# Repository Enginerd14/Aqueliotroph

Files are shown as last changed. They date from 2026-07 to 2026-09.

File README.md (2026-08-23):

# Aqueliotroph
Automated plant watering and sun tracking system to optimise conditions for growth

I made this project becuase I always forget to water my plants and they never get enough sunlight. As a result they never survive :(. The Aqueliotroph system directly combats this by moving the plant to optimise light and watering the plant when soil mositure is low. 

Inspiration behind the Name: 



## 3D model



## Schematic





## PCB







# Parts List

> **Note:** Only the PCB needs to be purchased. I already have all other parts available, so the cost should only be around **£5 / $7**.

| Item | Qty | Need to Buy | Price (£) | Link | Total (£) | Total ($) |
|---|---:|:---:|---:|---:|---:|---
| 600mm Aluminium extrusion | 1 | No | £7.00 | [Al extrusion 600mm](https://www.ebay.co.uk/itm/305167092557?var=604105049024) |52.67 |71.84
| Belt Pulley | 1 | No | £4.99 | [Belt Pulley](https://www.aliexpress.com/item/1005010636842055.html) |
| Belt idler | 1 | No | £3.85 | [Idler Pulley](https://www.aliexpress.com/item/1005008093251681.html) |
| V Wheels | 4 | No | £2.44 | [V Wheels](https://www.aliexpress.com/item/1005004275676552.html) |
| Flexible plastic tube | 1 | No | £1.47 | [PVC tube](https://www.aliexpress.com/item/1005009698880250.html) |
| DC motor | 1 | No | £2.12 | [DC pump 12V 60RPM](https://www.ebay.co.uk/itm/226921983677?var=526075182200) |
| DC Water Pump | 1 | No | £2.48 | [DC water pump](https://www.aliexpress.com/item/1005007587818206.html) |
| Limit Switches | 2 | No | £1.23 | [Limit switches](https://www.aliexpress.com/item/1005005924250789.html) |
| Moisture sensor | 1 | No | £2.59 | [Soil moisture sensor](https://www.ebay.co.uk/itm/235973021747?var=536444158439) |
| Wire | 1m | No | £0.80 | [Wire](https://www.aliexpress.com/item/1005007251965003.html) |
| 470µF and 0.1µF Capacitor | 3 | No | £3.99 | [Capacitors](https://www.ebay.co.uk/itm/227351789982?var=526553493681) |
| LCD Display | 1 | No | £2.21 | [LCD](https://www.aliexpress.com/item/1005005095893869.html) |
| 12V 3A power supply | 1 | No | £4.06 | [Power supply 12V 3A](https://www.aliexpress.com/item/4000494270389.html) |
| L293D | 1 | No | £1.36 | [L293D](https://www.aliexpress.com/item/1005010400118009.html) |
| Arduino Uno | 1 | No | £3.22 | [Arduino Uno R3](https://www.aliexpress.com/item/32768431306.html) |
| LDR | 1 | No | £0.84 | [LDR](https://www.aliexpress.com/item/1005008904534544.html) |
| 10K, 220Ω Resistor | 2 | No | £1.75 | [Resistors](https://www.aliexpress.com/item/32698175464.html) |
| 250K Potentiometer | 1 | No | £1.27 | [Potentiometer](https://www.aliexpress.com/item/1005009882075493.html) |
| **PCB** | **1** | **Yes** | **£5.00** | N/A |

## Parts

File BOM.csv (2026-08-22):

Item | Qty | Need to buy | Total Price £ | URL | TOTAL (£) | TOTAL ($) | Note: Only need to buy PCB as I have all other parts so total needed will be around $7
600mm Aluminium extrusion | 1 | N | 7 | Al extrusion 600mm | 52.67 | 71.84
Belt Pulley | 1 | N | 4.99 | Belt Pulley
Belt idler | 1 | N | 3.85 | Idler Pully
V Wheels | 4 | N | 2.44 | V Wheels
Flexible plastic tube | 1 | N | 1.47 | PVC tube
DC motor | 1 | N | 2.12 | DC pump 12v 60rpm
DC water Pump | 1 | N | 2.48 | DC water pump
Limit Switches | 2 | N | 1.23 | Limit switches
Moisture sensor | 1 | N | 2.59 | Soil moisture sensor
Wire | 1m | N | 0.8 | Wire
470uf and 0.1uf Capacitor | 3 | N | 3.99 | Capacitors
LCD Display | 1 | N | 2.21 | LCD
12V 3A power supply | 1 | N | 4.06 | Power supply 12V 3A
L293D | 1 | N | 1.36 | l293d
Arduino uno | 1 | N | 3.22 | arduino uno r3
LDR | 1 | N | 0.84 | LDR
10K, 220 Resistor | 2 | N | 1.75 | Resistors
250K Potentiometer | 1 | N | 1.27 | Potentiometer
PCB | 1 | Y | 5 | N/A

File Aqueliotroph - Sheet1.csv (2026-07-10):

Item | Qty | Need to buy | Total Price £ | URL | TOTAL (£) | TOTAL ($)
600mm Aluminium extrusion | 1 | N | 0 | N/A | 20.59 | 27.6
Driver Pulley | 1 | N | 0 | N/A
Idler Pulley | 1 | N | 0 | N/A
Flexible plastic tube | 1 | Y | 1.62 | ID8 x OD10mm Flexible pipe
DC motor | 1 | Y | 2.01 | 12V DC 60rpm motor
DC water Pump | 1 | Y | 3.33 | 12V DC water pump
Limit Switches | 3 | Y | 1 | 5pcs Limit Switches
Moisture sensor | 1 | Y | 0.59 | Moisture Sensor
470uf Capacitor | 2 | Y | 1.15 | 10pcs 470uf Capacitor
0.1uf Capacitor | 1 | Y | 0.89 | 100pcs 0.1uf capacitor
LCD Display | 1 | N | 0 | N/A
12V 3A power supply | 1 | N | 0 | N/A
Servo | 1 | N | 0 | N/A
L293D | 1 | N | 0 | N/A
Arduino uno | 1 | N | 0 | N/A
LDR | 1 | N | 0 | N/A
10K Resistor | 1 | N | 0 | N/A
220 Resistor | 1 | N | 0 | N/A
250K Potentiometer | 1 | N | 0 | N/A
PCB | 1 | Y | 5 | N/A
3D printed parts(delivery) | N/A | Y | 5 | N/A

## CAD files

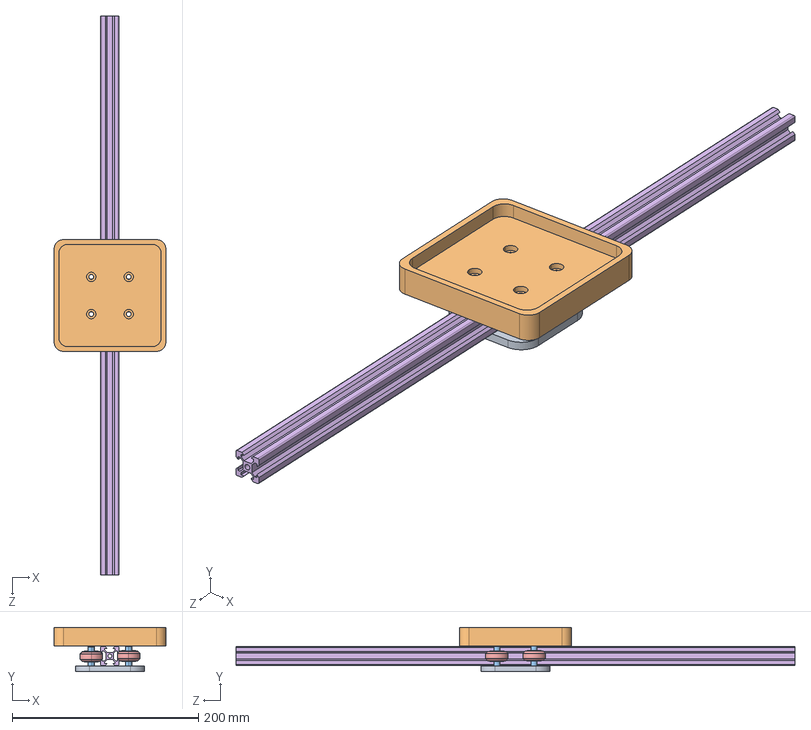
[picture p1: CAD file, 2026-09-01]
CAD/Parts(STEP)/PlantCarriageAssembly.STEP
120.0 x 47.4 x 600.0 mm
PlantCarriageBase
PlantCarriageTop
VWheelSpacer x 8
VWheel x 4
600mmAlExt

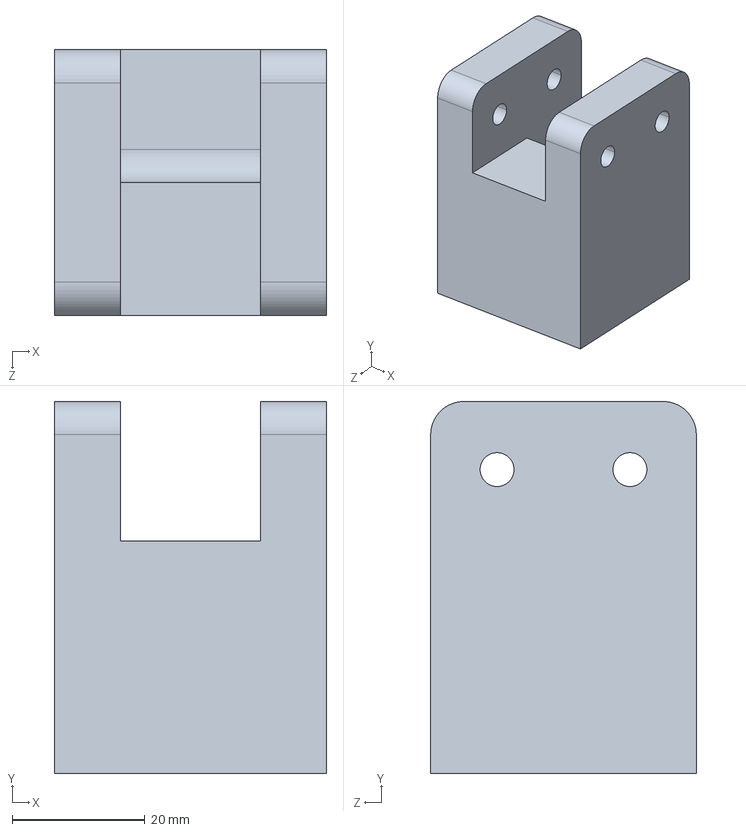
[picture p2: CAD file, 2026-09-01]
CAD/Parts(STEP)/StandIdler.step
41.0 x 56.0 x 40.0 mm

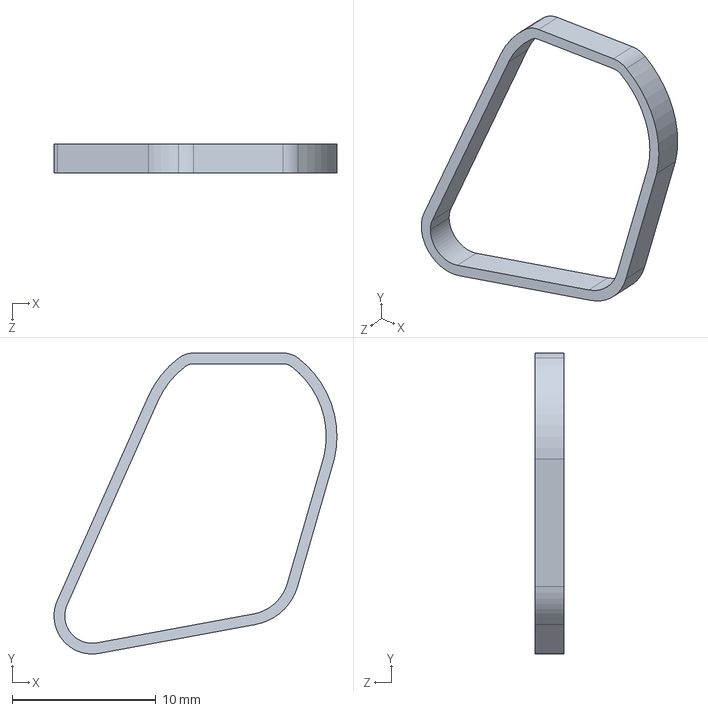
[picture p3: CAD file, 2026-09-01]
CAD/Parts(STEP)/Ziptie.step
19.7 x 20.9 x 2.00 mm

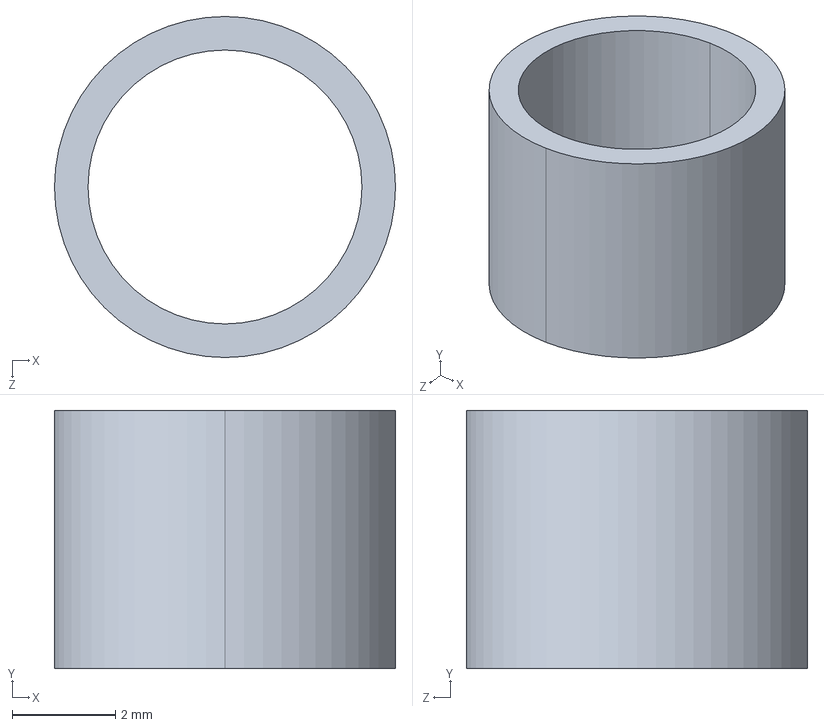
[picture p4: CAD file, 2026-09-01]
CAD/Parts(STEP)/VWheelSpacer.step
6.60 x 5.00 x 6.60 mm

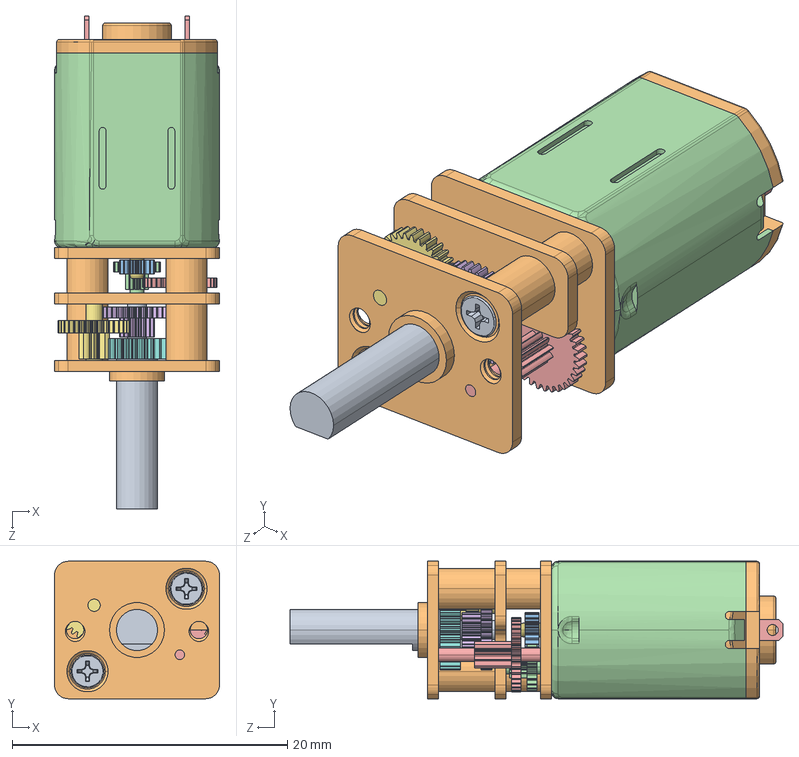
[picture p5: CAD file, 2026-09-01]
CAD/Parts(STEP)/Motor.STEP
12.0 x 10.0 x 35.9 mm
M1.4 10mm half thread.step x 2
Gearbox Casing.step
15T.step
9T 21T.step
10T 34T.step
15T 37T.step
8T 33T.step
27T.step
Motor.step
Shaft.step

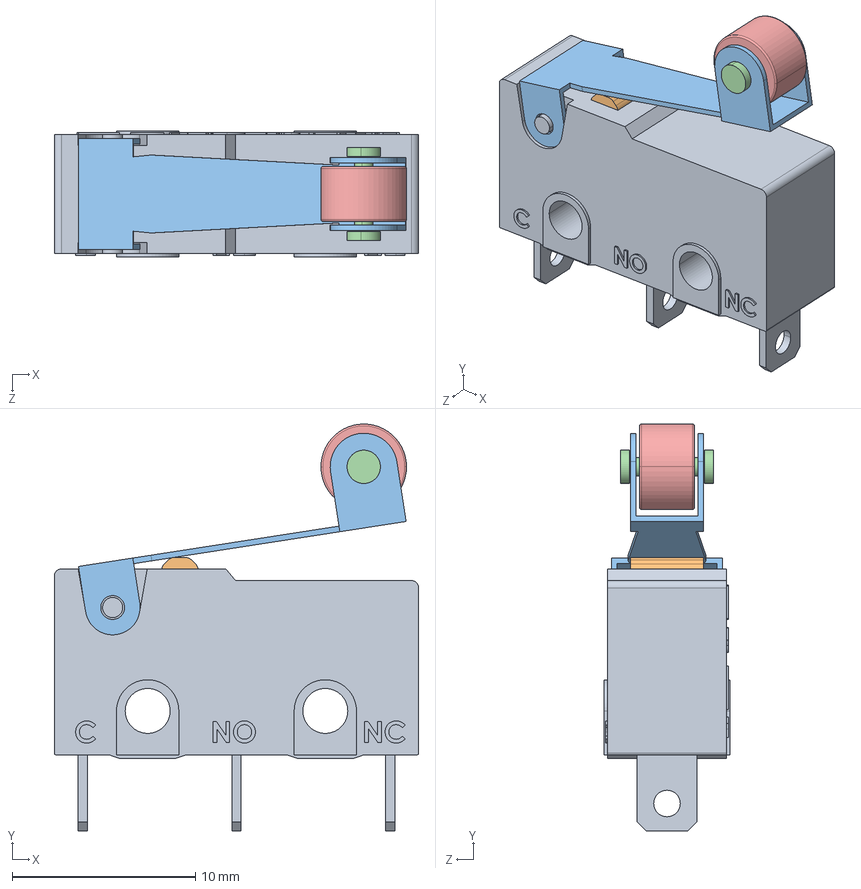
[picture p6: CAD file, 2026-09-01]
CAD/Parts(STEP)/Limit Switch.STEP
19.9 x 22.2 x 6.90 mm
Body.STEP
Switch_Button.STEP
Link.STEP
Wheel shaft.STEP
Wheel.STEP

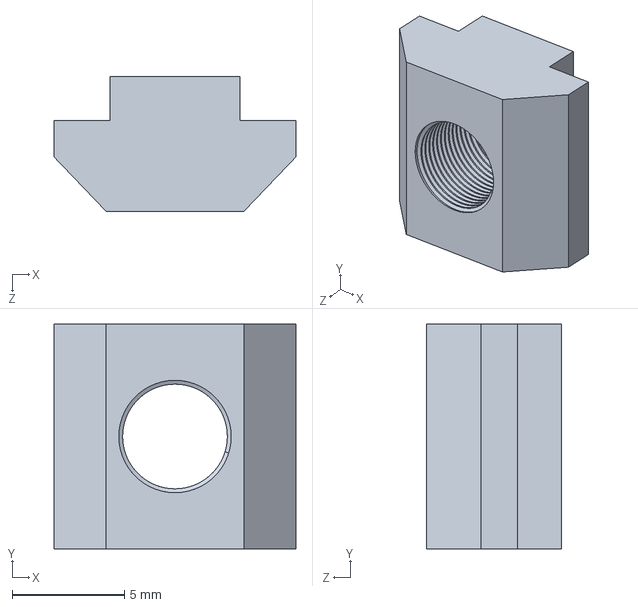
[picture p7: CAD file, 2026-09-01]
CAD/Parts(STEP)/AlExtrusionFixingNut.step
10.8 x 10.0 x 5.99 mm

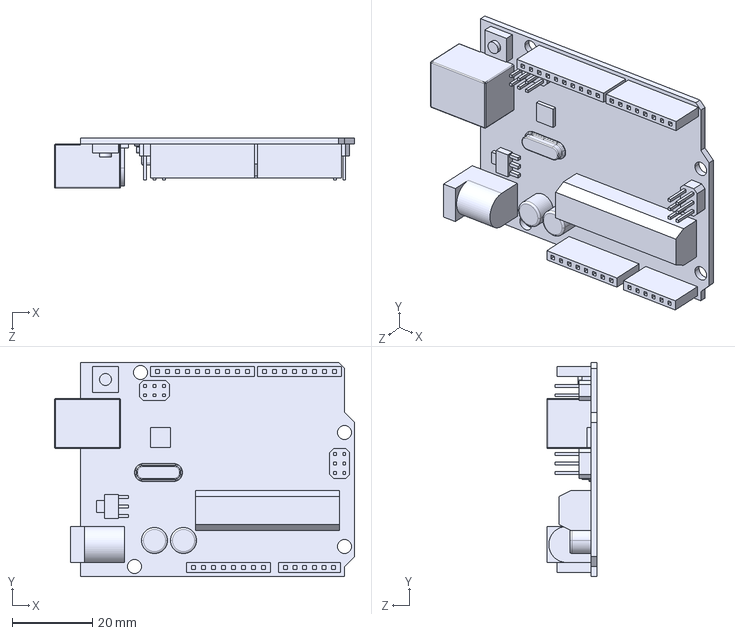
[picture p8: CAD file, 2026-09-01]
CAD/Parts(STEP)/Arduino_Uno.STEP
75.0 x 53.5 x 12.6 mm

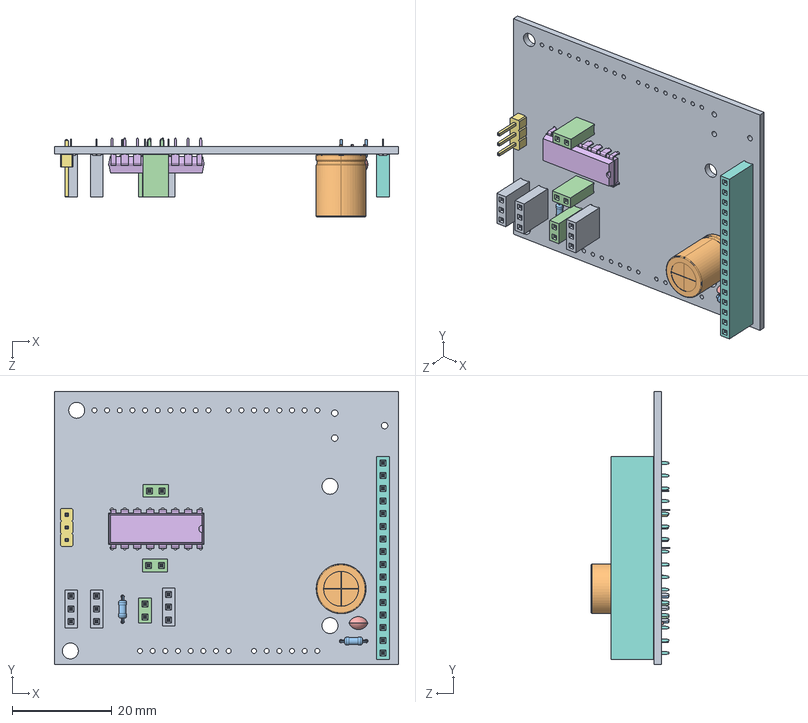
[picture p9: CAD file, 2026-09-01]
CAD/Parts(STEP)/AqueliotrophPCB.STEP
69.0 x 54.8 x 15.8 mm
PinSocket_1x03_P2.54mm_Vertical.step x 3
C_Radial_D10.0mm_H12.5mm_P5.00mm.step
R_Axial_DIN0204_L3.6mm_D1.6mm_P5.08mm_Horizontal.step x 2
PinSocket_1x02_P2.54mm_Vertical.step x 3
C_Disc_D3.8mm_W2.6mm_P2.50mm.step
DIP-16_W7.62mm.step
PinHeader_1x03_P2.54mm_Vertical.step
PinSocket_1x16_P2.54mm_Vertical.step
Aqueliotroph_PCB.step

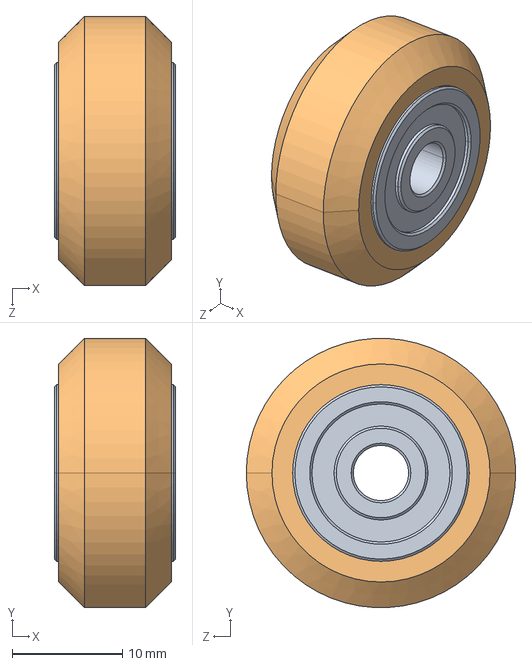
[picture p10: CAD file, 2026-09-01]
CAD/Parts(STEP)/VWheel.step
11.0 x 24.4 x 24.4 mm

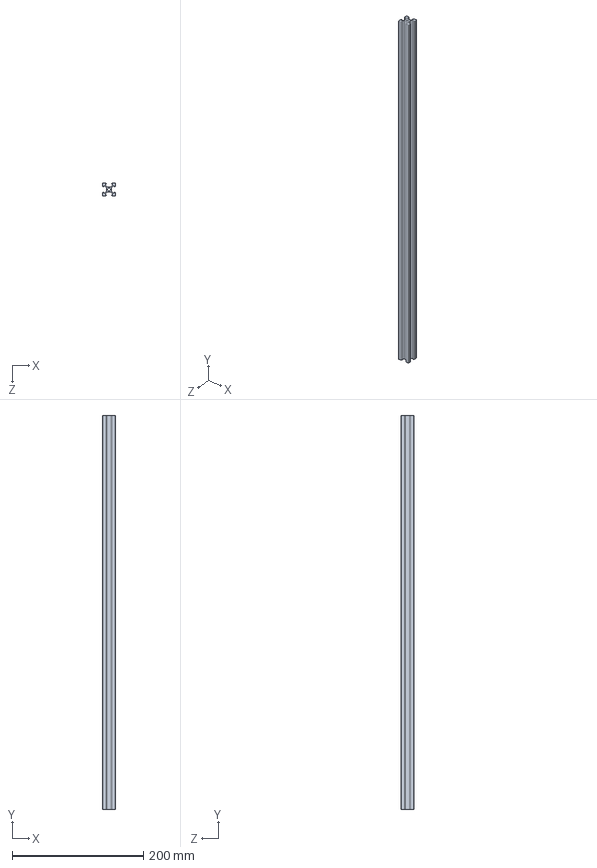
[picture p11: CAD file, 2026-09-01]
CAD/Parts(STEP)/600mmAlExt.step
20.0 x 600.0 x 20.0 mm

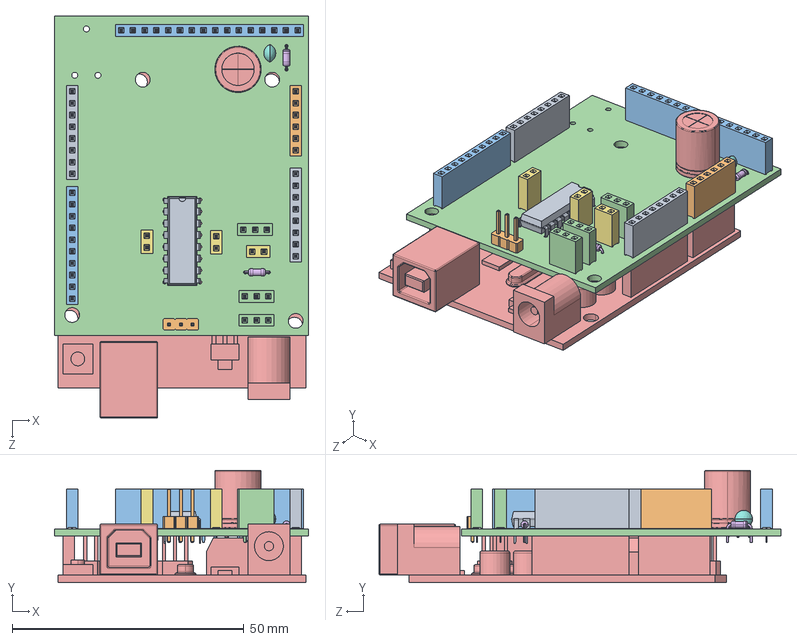
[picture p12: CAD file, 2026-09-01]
CAD/Parts(STEP)/ArduinoUnoR3.STEP
54.8 x 24.2 x 86.8 mm
PinSocket_1x08_P2.54mm_Vertical.step x 2
PinSocket_1x06_P2.54mm_Vertical.step
PinSocket_1x10_P2.54mm_Vertical.step
PinSocket_1x03_P2.54mm_Vertical.step x 3
C_Radial_D10.0mm_H12.5mm_P5.00mm.step
R_Axial_DIN0204_L3.6mm_D1.6mm_P5.08mm_Horizontal.step x 2
PinSocket_1x02_P2.54mm_Vertical.step x 3
C_Disc_D3.8mm_W2.6mm_P2.50mm.step
DIP-16_W7.62mm.step
PinHeader_1x03_P2.54mm_Vertical.step
PinSocket_1x16_P2.54mm_Vertical.step
Aqueliotroph_PCB.step
Arduino_Uno

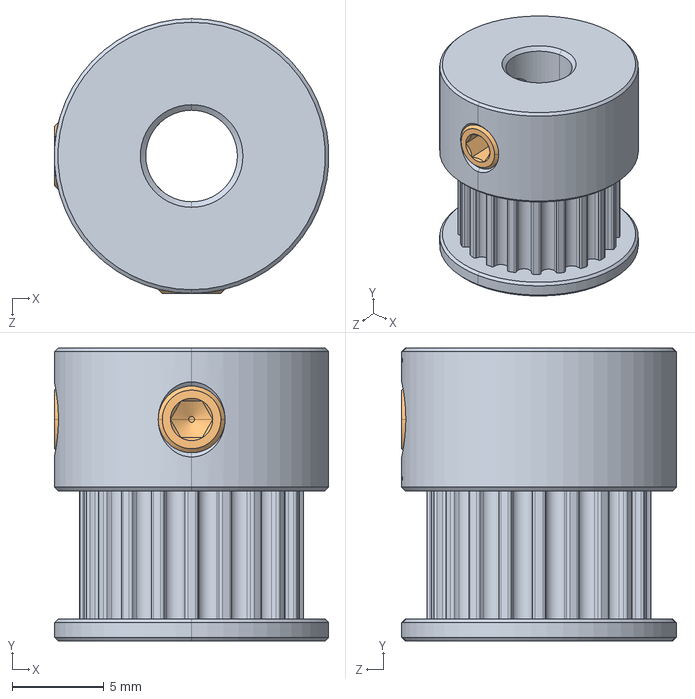
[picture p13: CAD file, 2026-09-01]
CAD/Parts(STEP)/GT2_Pully_20T_6mm.STEP
15.0 x 16.0 x 15.0 mm
GT2_Pulley_20T_6mm.step
M4x5-Screw028.step x 2

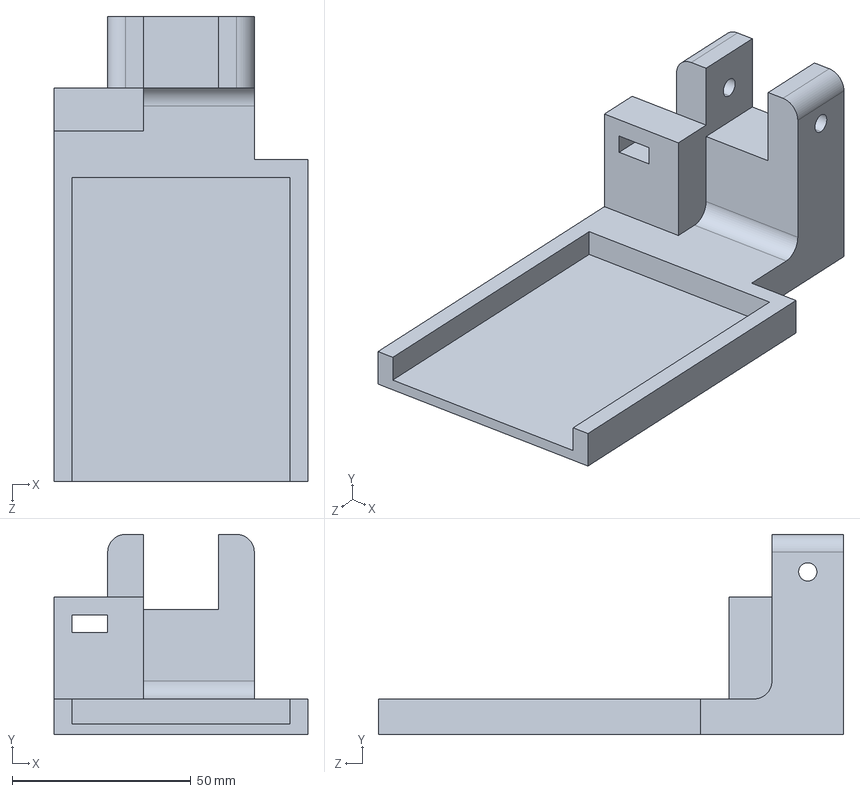
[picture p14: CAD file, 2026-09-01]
CAD/Parts(STEP)/StandMotor.step
71.0 x 56.0 x 130.0 mm

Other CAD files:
CAD/Parts(STEP)/PlantCarriageBase.step
CAD/Parts(STEP)/GT2_Idler_Smooth_6mm.STEP
CAD/Parts(STEP)/PlantCarriageTop.step

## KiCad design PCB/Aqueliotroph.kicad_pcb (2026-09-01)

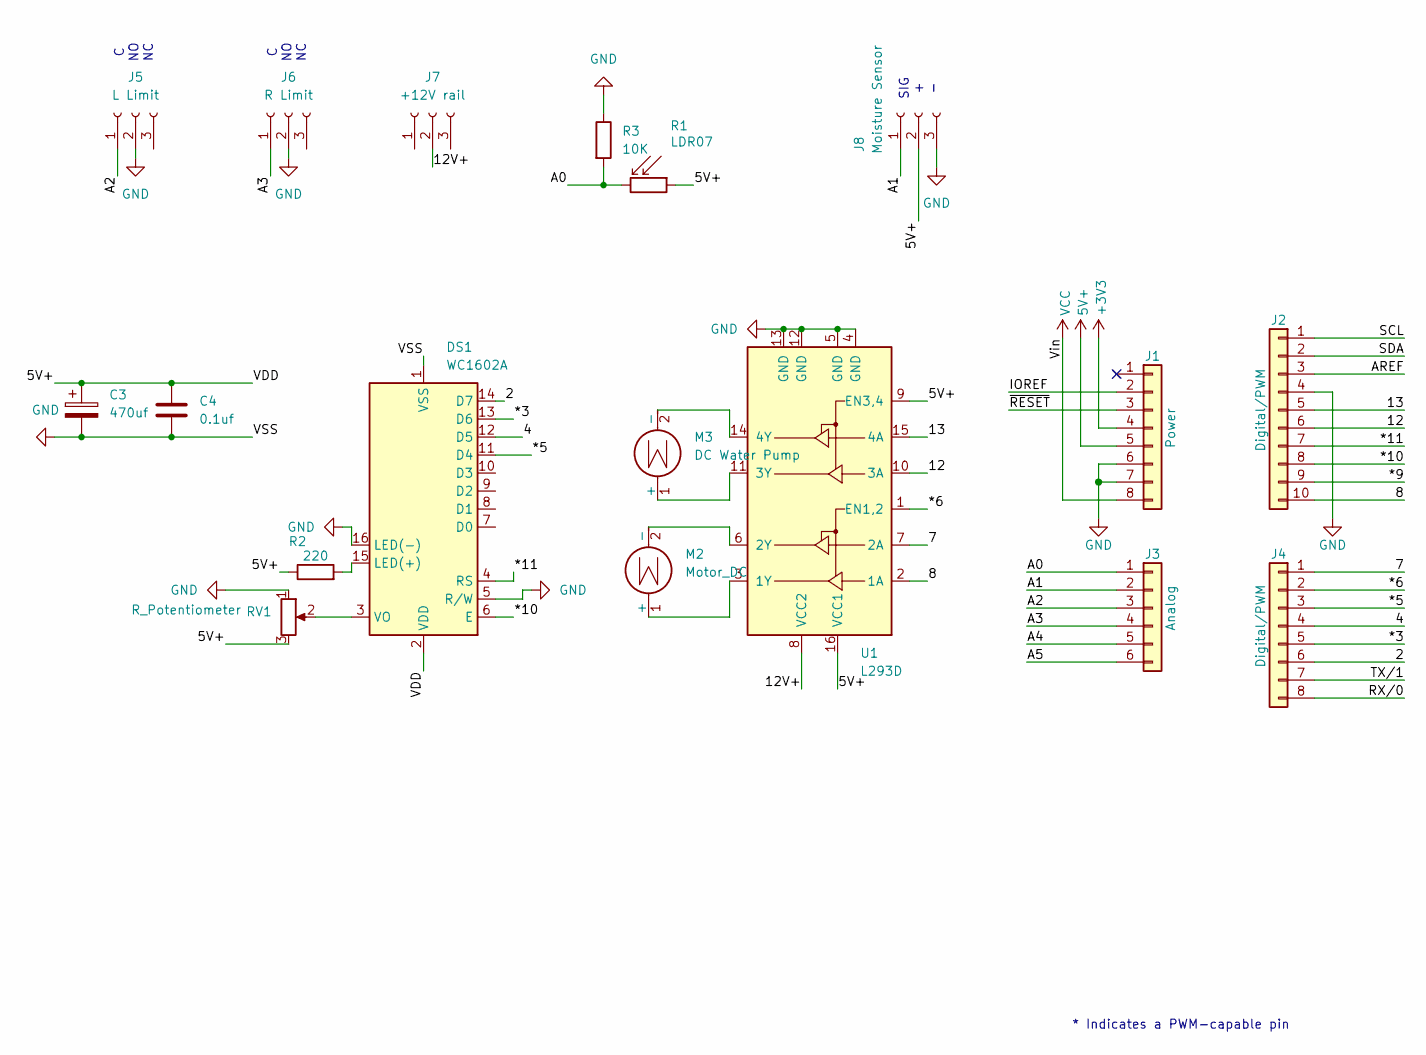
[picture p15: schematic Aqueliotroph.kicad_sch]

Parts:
C3: 470uf; C_Radial_D10.0mm_H12.5mm_P5.00mm
C4: 0.1uf; C_Disc_D3.8mm_W2.6mm_P2.50mm
DS1: WC1602A; PinSocket_1x16_P2.54mm_Vertical
J1: Power; PinSocket_1x08_P2.54mm_Vertical
J2: Digital/PWM; PinSocket_1x10_P2.54mm_Vertical
J3: Analog; PinSocket_1x06_P2.54mm_Vertical
J4: Digital/PWM; PinSocket_1x08_P2.54mm_Vertical
J5: L Limit; PinSocket_1x03_P2.54mm_Vertical
J6: R Limit; PinSocket_1x03_P2.54mm_Vertical
J7: +12V rail; PinHeader_1x03_P2.54mm_Vertical
J8: Moisture Sensor; PinSocket_1x03_P2.54mm_Vertical
M2: Motor_DC; PinSocket_1x02_P2.54mm_Vertical
M3: DC Water Pump; PinSocket_1x02_P2.54mm_Vertical
R1: LDR07; PinSocket_1x02_P2.54mm_Vertical
R2: 220; R_Axial_DIN0204_L3.6mm_D1.6mm_P5.08mm_Horizontal
R3: 10K; R_Axial_DIN0204_L3.6mm_D1.6mm_P5.08mm_Horizontal
RV1: R_Potentiometer; Potentiometer_Piher_PT-10-V10_Vertical
U1: L293D; DIP-16_W7.62mm

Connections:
5V+: C3.1, C4.1, DS1.2 (VDD), J1.5, J8.2, R1.1, R2.1, RV1.3, U1.9 (EN3,4), U1.16 (VCC1)
+3V3: J1.4
/2: DS1.14 (D7), J4.6
/4: DS1.12 (D5), J4.4
/7: J4.1, U1.7 (2A)
/8: J2.10, U1.2 (1A)
/12: J2.6, U1.10 (3A)
/12V+: J7.2, U1.8 (VCC2)
/13: J2.5, U1.15 (4A)
/*3: DS1.13 (D6), J4.5
/*5: DS1.11 (D4), J4.3
/*6: J4.2, U1.1 (EN1,2)
/*9: J2.9
/*10: DS1.6 (E), J2.8
/*11: DS1.4 (RS), J2.7
/A0: J3.1, R1.2, R3.2
/A1: J3.2, J8.1
/A2: J3.3, J5.1
/A3: J3.4, J6.1
/A4: J3.5
/A5: J3.6
/AREF: J2.3
/IOREF: J1.2
/RX/0: J4.8
/SCL: J2.1
/SDA: J2.2
/TX/1: J4.7
/~RESET: J1.3
GND: C3.2, C4.2, DS1.1 (VSS), DS1.5 (R/W), DS1.16 (LED(-)), J1.6, J1.7, J2.4, J5.2, J6.2, J8.3, R3.1, RV1.1, U1.4 (GND), U1.5 (GND), U1.12 (GND), U1.13 (GND)
unnamed: DS1.15 (LED(+)), R2.2
unnamed: DS1.3 (VO), RV1.2
unnamed: M2.1 (+), U1.3 (1Y)
unnamed: M2.2 (-), U1.6 (2Y)
unnamed: M3.1 (+), U1.11 (3Y)
unnamed: M3.2 (-), U1.14 (4Y)
VCC: J1.8

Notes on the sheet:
C NO NC
* Indicates a PWM-capable pin
SIG + -

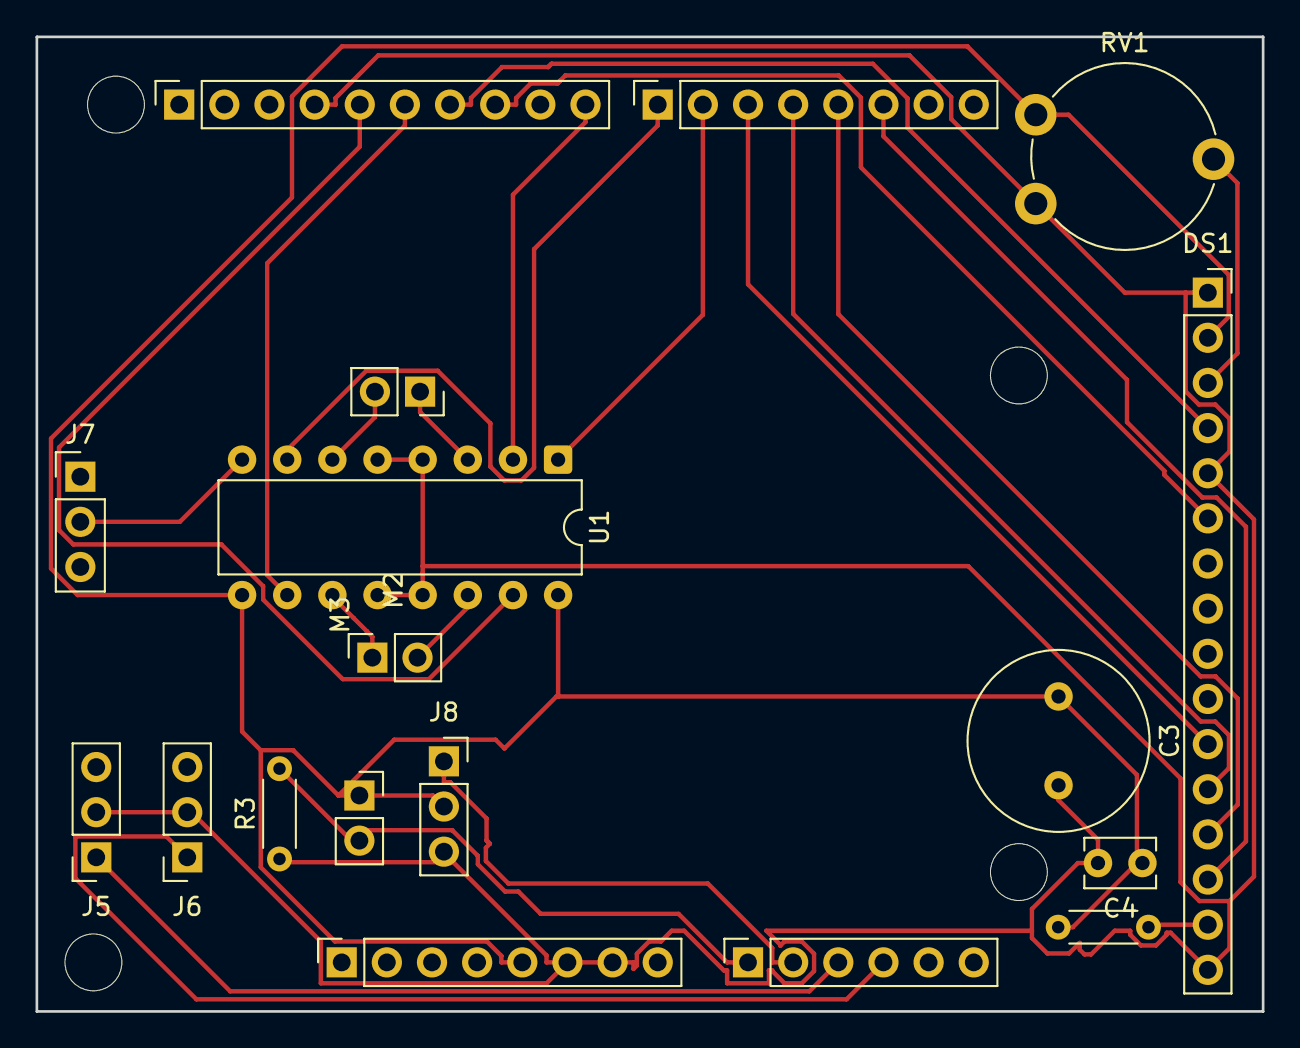
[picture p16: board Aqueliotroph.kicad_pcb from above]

Board: 2 copper layers, 69.0 x 54.8 mm, 22 parts (0 on the bottom side), 24 nets.

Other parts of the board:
MH1, MH2, MH3, MH4: MountingHole_3.2mm

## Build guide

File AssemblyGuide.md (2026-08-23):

## Step 1

Use 4x 16mm M5 screws with 4 M5 sliding bolts to attach the Idler stand and motor stand to the aluminium extrusion. 

## Step 2

Using 8x spacers with 4x V wheels and 4x 40mm M5 screws with nuts, attach the plant top and plant base together to create a plant carriage which can slide along the extrusion. 

## Step 3

Use a 30mm M5 screw to attach the idler wheel to the idler stand. Then use zip ties to secure the motor to the motor stand and use the grub screws to fix the pulley wheel to the motor.

## Step 4

Then, thread the pulley bet through the top of the extrusion and around the pulley and idler wheels and wrap through the hole in the plant base and secure with zip ties.

Finished! The Aqueliotroph frame is assembled. 

Note: This assembly guide will be improved once I complete the project. This is just for a rough understanding for now.

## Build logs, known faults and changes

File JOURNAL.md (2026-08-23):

## 2nd July 2026: Wiring and schematics
I began the project by creating a schematic for all the wiring of the components. I decided to use an arduino uno: I know it's outdated and there are better microcontroller boards but the circuit components for this project are very simple and I already had two availale. I first decided to do this in KiCad however the pin numbering and labelling was confusing me so I switched over to tinker cad as I was using an arduino uno. This made it much easier to create a full schematic. Then I used really basic code to just simply test each component by produing a basic output on the simulation and confirmed the wiring was correct. 

Schematic:



Lapse: https://lapse.hackclub.com/timelapse/tBaE92BHizNh

Time Spent: 00:41

## 2nd July 2026: Building the circuit 
I asssembled the circuit using the arduino uno kit I already had and following my functioning schematic. However after uploading the code to test it, the components did not seem to be working. I could hear a slight clicking sound from the servo but no movement, the motor did not seem to do anything and the LCD was not even turning on so I had no idea whether the LDR was functioning. I double checked the wiring against the schematic and couldn't find an issue. I will troubleshoot each component individually later when I have more time. 

Circuit:



Lapse: https://lapse.hackclub.com/timelapse/c16ZF1C1VSLh

NOTE: For some reason after 0:06, it stopped taking pictures and is stuck on the same picture, I didn't realise until I finished the circuit. I have a picture of the finished circuit timestamped if that helps

Timestamped photo:



Time Spent: 00:36

## 2nd and 3rd July 2026: Designing the model in CAD (Solidworks)
I moved on to creating the design of the product in Solidworks to take a break from circuitry. I based my design of components I already had for a previous project such as 600mm 2020 aluminium extrusion and 6mm pulley belt and pulleys. I created a gantry carraige for the plant to sit on and I plan to attach the pulley belt to this carriage so that as the motor moves, the plant carriage would move too. This will allow it to change positions to optimse sunlight. I then began creating the stands tha would suspend the extrusion in the air. I added in a cut out at the top for the limit switches. Then i moved on to creating a simple rough stand and container to visualise the watering system. I will likely not 3D print this and will use scrap materials around the house for this stand. The idea is I will use the servo to crimp the tube to stop water flowing and then uncrimp it and let gravity take control to water the plant. Once I had made the stand for the water container, I had to edit the stands of the extrusion for the servo. I also filleted the edges to improve overall appearance. 



2nd July Lapse: https://lapse.hackclub.com/timelapse/DHAjXOzbIMxc     01:42:23

3rd July Lapse: https://lapse.hackclub.com/timelapse/Rks5L6Anx1pu     01:06:49

Time Spent: 02:49

## 4th July 2026: Fixing the circuit
I had a look at the circuit again today and first checked everything against the schematic. As far as I could tell, everything was wired correctly so I tested it again but no change. I then used my other arduino uno to see if I was usign a faulty uno but neither of them worked. So I decided to rewire everything but test it in little bits instead. I began with the LCD and this time I got it to turn on but it didn't diaply anything. After further inspection, it turned out I forgot to wire RW to gnd. Once I did this it functioned perfectly. Then I moved onto the LDR which worked perfectly as expected. Then I moved onto the servo which worked after a little bit of thinking as it turned out the code had the wrong pin for the servo. Then I tried the motor but I couldn't get it to work. I tried to power it all through 12v but that failed to work too. After a lot of testing it turned out there was some conflict between the servo and the motor due to pin 9 so I changed the motor to connect to pin 6 for pwm and then rewired the l293d to the arduino and this time it worked. 

Lapse: https://lapse.hackclub.com/timelapse/w8Zyqny9Opo1     00:05:00

Lapse: https://lapse.hackclub.com/timelapse/GnqO4-OK7IQY     01:17:00

NOTE: It happened again :( after 8 minutes it stopped taking pictures. I have timestamped videos and pictures throughout the time (attached below) but no continuous video.



markup_1000019334

markup_1000019333

markup_1000019332





I spent another half an hour at night that I didn't bother to use lapse for becuase it wasn't working so I have included a timestamped photo below.

markup_1000019342

Video of working circuit:

https://youtu.be/JYhf91gpHcE

Time Spent: 01:52

## 5th July 2026: Designing the PCB
I designed my PCB so that it could be like a shield and stack on top of the arduino uno. I used an arduino uno footprint as a template to place everything in the correct place before removing the footprint and adding in pin sockets where they would be on the arduino uno. I then added in all the trace lines to complete the PCB.





Lapse: https://lapse.hackclub.com/timelapse/jVmM2SpNe8C-

Time Spent: 2:00

## 5th July 2026: Fixing the CAD model
I changed the stand on the right to accomodate the motor and also a PCB and realised that the square hole for the extrusion was too small so resized that. As I was fixing the model, I realised I forgot the V-wheels for the plant pot carriage so will have to redesign that tomorrow :(



Lapse: https://lapse.hackclub.com/timelapse/tX8e8igjWN-x 

Time Spent: 00:29

## 7th July 2026: Fixing the CAD model
I first added a moisture sensor into the circuit. Then, I had to redesign the entire plant carriage assembly. This means I will have to reassemble the main assembly all over again tomorrow. To add v wheels to the plant carriage I had to spit it into two bodies and will use a 40mm M5 screw to fix the two bodies together adding v wheels inbetween. 





Lapse: https://lapse.hackclub.com/timelapse/ZRIUK9M7NHi8

Time Spent: 02:06

## 8th July 2026: Adding to circuit and fixing the CAD model
I added another motor to the breadbaord schematic on tinkercad as a placeholder for a DC water pump. I will attempt to avoid buying and having to use the water pump and will attempt my servo method first but I'm keeping the option open. I then increased the height of the stands and fixed the final assembly. 





Lapse: https://lapse.hackclub.com/timelapse/WA_zX9wjQfdF 

(I added an extra 20mins to the final time becuase I spent some time adding spaces for the nuts for fixing the two halves of the carriage but forgot to record it with Lapse.)

Time Spent: 01:07 

## 9th July 2026: Fixing Kicad Schematic and PCB
I added in the final components to the schematic and realised that the PCB footrpint for the uno was reversed. This meant I had to remake the entire PCB and schematic using a template instead of a footprint. This was harder than using the reversed footrpint as the top row of digital pins were heavily used so it was difficult to add traces that didn't intersect. Eventually I resorted to oversizing the PCB so that I didn't have to use any wires or 0ohm resistors as jumpers. 







Lapse: https://lapse.hackclub.com/timelapse/YqrEKAufjbH9

(Lapse or google or smth crashed halfway through and I didn't realise so I have added 30mins on to final time for the work that was not recorded.)

Time Spent: 01:42 

## 9th July 2026: Adding in limit switches to schematic and PCB
I checked the size of the PCB and found that it was around 55mmx85mm which is well below JLCPCB's limit. Then I checked whether the space in the stand that will be 3D printed is big enough for the PCB and it was perfectly sized. Afterwards, I realised I forgot the limit switches so I went back to the breadboard on tinkercad and added them to pin A2 and A3 as I ran out of digital pins. Then I added in the code to be able to test the switches and found that they worked as expected. Then I added in two 1x03 pin sockets to the PCB for the limit switches to connect to. 











Time Spent: 00:47 

## 10th July 2026: Writing the code
I began writing the code for the project using VS code and recording my time spent using hackatime. I wrote the code so that the project functions like this: 

- To track sunlight: the Plant pot carriage will have an LDR and will move to 5 different positions on the aluminium extrusion and will record where light was highest and will move to that position to optimise sunlight
- To water plant: I decided to use the pump method as everything about it is just simpler and more fool proof. This works by just using the soil moisture sensor to detect low moisture levels in soil and trigger pump to release water
- I then added in code to display the details on the LCD



Time Spent: 01:43 

## 16th July 2026: Fixing the models
The models I had designed were requiring too much filament and time to print mainly because of the supports due to overhangs. Thus, I decided to redesign  the parts completely. As I am now using the pump instead of the servo to water the plant I reduced the length of the stand and removed the overhang so no need for support there. Then I looked at the plant carriage. I took inspiration from my pen plotter project and completely simplified it so that there were no overhangs. I couldn't really do much on the other stand but there was one overhang that I managed to remove. I then had to recreate the assembly but this time it was much smaller and simpler as I was not using the servo and gravity to water the plant. 







Time Spent: 00:45

## 5th August 2026: Responding to review

I removed the servo from my PCB and schematic and updated the BOM. Then I looked into adding a pulley belt into my CAD model to show the movement of the carriage. The idea is that when the motor rotates, it pulls on the pulley belt which is fastened to the plant carriage thus dragging the plant carriage along with it. The last image uses the red pen to show how the belt will attach to the carriage (sorry my CAD skills aren't good enough to add that in the model directly).







https://lapse.hackclub.com/timelapse/5MZtIGj5UeVw

Time Spent: 00:22

## 6th August 2026: Responding to review

My computer crashed and didn't save any of the work so I had to redo the belt. Then I modelled a zip tie to show how the motor will be fixed to the 3D printed parts and finished off by adding the PCB mounted on the Arduino UNO R3. I had to add all the CAD files onto github as a zip folder to compress them as github only has a 25mb file limit.



https://lapse.hackclub.com/timelapse/rQG-F8ZIK_1B

Time Spent: 00:42

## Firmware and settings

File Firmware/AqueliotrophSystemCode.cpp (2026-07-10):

#include <LiquidCrystal.h>
#include <Servo.h>

//Pins

LiquidCrystal lcd(11,10,5,4,3,2);

Servo myservo;
const int ServoPin = 9;

//Sensors
const int ldrPin = A0;
const int moisturePin = A1;

//Limti Switches
const int LlimitPin = A2;
const int RlimitPin = A3;

//Pulley motor
const int motorIN1 = 8;
const int motorIN2 = 7;
const int motorEN = 6;

//Pump
const int motorIN3 = 12;
const int motorIN4 = 13;

//Settings
const int moistureThreshold = 700;
const int lightChangeLimit = 50;

//Pos Settings
const int moveTime = 800; // time in ms betwwen positions

int currentPos = 1;
int bestPos = 1;
int prevLight = 0;

unsigned long lastSearch = 0;
unsigned long searchInterval = 300000; // 300000ms = 5 mins

void setup() {
    Serial.begin(9600);

    lcd.begin(16,2);
    lcd.print("Aqueliotroph system starting...");
    delay(2000);
    lcd.clear();

    pinMode(LlimitPin, INPUT_PULLUP);
    pinMode(RlimitPin, INPUT_PULLUP);

    pinMode(motorIN1, OUTPUT);
    pinMode(motorIN2, OUTPUT);
    pinMode(motorEN, OUTPUT);

    pinMode(motorIN3, OUTPUT);
    pinMode(motorIN4, OUTPUT);

    stopCarriageMotor();
    stopPump();

    Calibrate();

    prevLight = analogRead(ldrPin);

    SunScan();
}

void loop() {
    int light = analogRead(ldrPin);

    if(abs(light - prevLight) > lightChangeLimit) {
        SunScan();
        prevLight = light;
    }

    if (millis() - lastSearch > searchInterval) {
        SunScan();
        lastSearch = millis();
        prevLight = analogRead(ldrPin);
    }

    checkMoisture();
    displayInfo();
    delay(500);
}

// Scanning for Sun

void SunScan() {
    lcd.clear();
    lcd.print("Scanning for best light...");

    int bestLight = 0;
    bestPos = 1;

    for (int pos =1; pos <=5; pos++) {
        moveToPosition(pos);

        delay(500);

        int light = analogRead(ldrPin);

        Serial.print("Position ");
        Serial.print(pos);
        Serial.print(" = ");
        Serial.println(light);

        if (light > bestLight) {
            bestLight = light;
            bestPos = pos;

        }
    }

    moveToPosition(bestPos);

    lcd.clear();
    lcd.print("Best Position:");
    lcd.setCursor(0,1);
    lcd.print(bestPos);

    delay(2000);
}

//Positioning

void moveToPosition(int targetPosition) {
    while (currentPos < targetPosition) {
        moveOneRight();
        currentPos++;
    }
    while (currentPos > targetPosition) {
        moveOneLeft();
        currentPos--;
    }
}

void moveOneRight() {
    if (digitalRead(RlimitPin) == LOW) {
        stopCarriageMotor();
        return;
    }

    digitalWrite(motorIN1, HIGH);
    digitalWrite(motorIN2, LOW);
    analogWrite(motorEN, 180);

    delay(moveTime);

    stopCarriageMotor();

    delay(300);
}

void moveOneLeft() {
    if (digitalRead(LlimitPin) == LOW) {
        stopCarriageMotor();
        return;
    }

    digitalWrite(motorIN1, LOW);
    digitalWrite(motorIN2, HIGH);
    analogWrite(motorEN, 180);

    delay(moveTime);

    stopCarriageMotor();

    delay(300);
}

void stopCarriageMotor() {
    digitalWrite(motorIN1, LOW);
    digitalWrite(motorIN2, LOW);
    analogWrite(motorEN, 0);
}

//Calibrate

void Calibrate() {
    lcd.clear();
    lcd.print("Calibrating...");

    digitalWrite(motorIN1, LOW);
    digitalWrite(motorIN2, HIGH);
    analogWrite(motorEN, 180);

    while (digitalRead(LlimitPin) == HIGH) {
        delay(10);
    }

    stopCarriageMotor();

    currentPos = 1;

    lcd.clear();
    lcd.print("Found Home");
    delay(1000);
}

// Watering

void checkMoisture() {
    int moisture = analogRead(moisturePin);

    if (moisture > moistureThreshold){
        waterPlant();
    }
}

void waterPlant() {
    lcd.clear();
    lcd.print("Watering...");

    Serial.println("Pump is on");

    digitalWrite(motorIN3, HIGH);
    digitalWrite(motorIN4, LOW);

    delay(3000);

    stopPump();

    Serial.println("Pump is off");

    delay(1000);
}

void stopPump() {
    digitalWrite(motorIN3, LOW);
    digitalWrite(motorIN4, LOW);    
}

// Display on LCD

void displayInfo() {
    int light = analogRead(ldrPin);
    int moisture = analogRead(moisturePin);

    lcd.clear();

    lcd.setCursor(0, 0);
    lcd.print("Light:");
    lcd.print(light);
    Serial.print("Light: ");
    Serial.print(light);

    lcd.setCursor(9, 0);
    lcd.print("Pos:");
    lcd.print(currentPos);
    Serial.print(" Position: ");
    Serial.println(currentPos);

    lcd.setCursor(0, 1);
    lcd.print("Moisture:");
    lcd.print(moisture);
    Serial.print(" Moisture: ");
    Serial.print(moisture);
}

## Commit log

2026-07-03 Update JOURNAL.md with project progress and issues
    Documented the progress of wiring, circuit assembly, and CAD design for the project, including issues encountered and time spent on each task.
2026-07-05 Enhance journal entry with detailed testing notes
    Updated the journal entry with additional details about circuit testing and issues encountered. Included links to time-lapse videos and images for better documentation.
2026-07-05 Add entry for PCB design on 5th July 2026
2026-07-05 Update PCB design journal entry with images
    Added images and time spent for PCB design entry.
2026-07-06 Add journal entry for CAD model adjustments
    Added journal entry for fixing the CAD model, including changes made and time spent.
2026-07-08 Update JOURNAL.md with recent CAD and circuit changes
    Added details about circuit modifications and CAD fixes.
2026-07-09 Revise JOURNAL.md for clarity and corrections
    Updated the journal entries with improved clarity and fixed typos. Added details about the design process and troubleshooting steps for the circuit and CAD model.
2026-07-10 Document Kicad schematic and PCB updates
    Added details about fixing the Kicad schematic and PCB, including the addition of limit switches and pin sockets.
2026-07-10 Update journal entry for limit switches addition
2026-07-10 Update README to include schematic and PCB images
    Added schematic, PCB, and BOM sections with images.
2026-07-10 Update BOM table to include total prices in GBP and USD
2026-07-10 Add Aqueliotroph - BOM.csv file
    [Aqueliotroph - BOM.csv]
2026-07-10 Rename Aqueliotroph - BOM.csv to BOM.csv
    [BOM.csv]
2026-07-17 Redesign models to optimize printing efficiency
    Redesigned models to reduce filament usage and printing time by eliminating overhangs and supports. Updated assembly for simplicity.
2026-08-06 Rename Aqueliotroph - Sheet1 (1).csv to BOM.csv
    [BOM.csv]
2026-08-22 Revise parts list and BOM in README
    Updated the parts list and BOM with new items and links.
2026-08-23 Update journal entry with CAD file upload details
    Added details about uploading CAD files to GitHub due to file size limitations.
2026-08-23 Document assembly steps for Aqueliotroph frame
    Added detailed assembly steps for the Aqueliotroph frame.
2026-09-01 Uploaded STEP assembly file
2026-09-01 Uploaded PCB project Files
    [Aqueliotroph.kicad_pcb, Aqueliotroph.kicad_sch]
